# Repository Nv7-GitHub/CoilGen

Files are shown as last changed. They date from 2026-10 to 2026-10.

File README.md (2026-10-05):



## **IMPORTANT BUG FIX REGARDING FIELD SCALE IN "plot_various_error_metrics" PLOT - PLEASE UPDATE!**

 

<!-- ABOUT THE PROJECT -->

The CoilGen Project is a community-based tool for the generation of coil Layouts within the MRI/NMR environment. It is based on a boundary element method and generates an interconnected non-overlapping wire-tracks on 3D support structures. The focus of this work is post processing.

The user must specify a target field (e.g., bz(x,y,z)=y for a constant gradient in the y-direction) and a surface mesh geometry (e.g., a cylinder defined in an .stl file). The code then generates a coil layout in the form of a non-overlapping, interconnected wire trace to achieve the desired field.

## pyCoilGen: A Python Implementation
The author has supported the creation of **pyCoilGen**, a translation of this CoilGen Project to Python. The code is available on [GitHub](https://github.com/kev-m/pyCoilGen) and
documentation is available on [ReadTheDocs](https://pycoilgen.readthedocs.io/).

A full description is given in the following publication: https://onlinelibrary.wiley.com/doi/10.1002/mrm.29294

<!-- GETTING STARTED -->
## Getting Started

Check the documentation to get started

### Installation

1. Download and extract the file of the CoilGen repository
2. Run one of the examples in the folder "Examples"

The project requires MATLAB and optionally FastHenry2 for calculation of the coil inductance.  The MATLAB version should not be older than 2020A.

### Flex PCB export for KiCad

Cylindrical coils can be built as rolled 2-layer flex PCBs:
- **Slit-cylinder design:** the coil is designed on a cylinder with an axial slit (`'create slit cylinder mesh'`), so no track crosses the seam of the rolled board.
- **Export:** `export_kicad_flex_pcb` writes a KiCad board with both layers in series, variable-width traces and design rules, so KiCad's DRC checks every turn.
- **Re-simulation:** `import_kicad_flex_pcb` reads the board back and re-simulates the manufactured copper with CoilGen. The result works with the plotting functions.

See [Documentation/KiCad_flex_PCB_export.md](Documentation/KiCad_flex_PCB_export.md). The examples are:
- `Examples/halbach_flex_pcb_gradient_set.m`, which designs, exports, checks and re-simulates a 3-axis gradient set for a small Halbach magnet;
- `Examples/view_flex_pcb_coils.m`, which shows that set in 3D;
- `Examples/check_flex_pcb_boards.m`, which runs the independent board checks (KiCad DRC, same-net clearance, manufacturer limits, full-width field).

Manufacturer stackups and limits are kept as JSON profiles in `KiCad_flex_PCBs/fab_profiles/` (JLCPCB 2-layer flex, 1 oz, 0.2 mm for the example). Each board also has a STEP model of the rolled board (`<coil>.step.zip`: board, copper and silkscreen as separate colored bodies) made with `export_rolled_step`. Regenerate it whenever the board changes.

### Algorithm overview

plot

<!-- LICENSE -->
## License

 See `LICENSE.txt` for more information.

<p align="right">(<a href="#top">back to top</a>)</p>

<!-- CONTACT -->
## Contact

Philipp Amrein, Github User: Philipp-MR 

Project Link: [https://github.com/Philipp-MR/CoilGen]

<p align="right">(<a href="#top">back to top</a>)</p>

## Citation

For citation of this work, please refer to the following publication:
https://onlinelibrary.wiley.com/doi/10.1002/mrm.29294
https://doi.org/10.1002/mrm.29294

<p align="right">(<a href="#top">back to top</a>)</p>

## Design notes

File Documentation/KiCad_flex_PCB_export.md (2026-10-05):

# Flex PCB gradient coils with CoilGen and KiCad

This guide covers the full workflow for building CoilGen coils as rolled 2-layer flex PCBs:

1. Design the coil on a cylinder with a slit (the seam of the rolled board).
2. Pick the manufacturer profile (stackup, limits, design values).
3. Export it as a KiCad board with both copper layers in series, the stackup and design rules included, plus a STEP model of the rolled board.
4. Check the board: KiCad's DRC, a same-net check the DRC can't do, and the manufacturer limits.
5. Read the board back into CoilGen and re-simulate the copper that will actually be made.
6. Look at the coils in 3D with CoilGen's plotting functions.
7. Build and align the coils.

The worked example is a 3-axis gradient set for a 45 mT Halbach magnet: `Examples/halbach_flex_pcb_gradient_set.m`. It runs steps 1–5 for all three coils.

| File | Purpose |
|---|---|
| `sub_functions/build_slit_cylinder_mesh.m` | Cylinder mesh with an axial slit (`'create slit cylinder mesh'`). |
| `sub_functions/export_kicad_flex_pcb.m` | CoilGen result → `.kicad_pcb` + `.kicad_pro`. |
| `sub_functions/import_kicad_flex_pcb.m` | `.kicad_pcb` → CoilGen result, re-evaluated with CoilGen's own field routines. |
| `sub_functions/strip_coilgen_result.m` | Keeps only the fields the plotting functions need, so a result can be saved compactly. |
| `Examples/halbach_flex_pcb_gradient_set.m` | Designs, exports, checks and re-simulates the Halbach gradient set. |
| `sub_functions/export_rolled_step.m` | STEP model of the board rolled onto its cylinder (board body, copper, silkscreen as separate colored bodies), zipped for git. |
| `sub_functions/rolled_flex_pcb_step.py` | Builds that STEP: reads the board with KiCad's Python module and wraps it onto the cylinder with OpenCASCADE. |
| `sub_functions/find_kicad_cli.m` | Locates KiCad's command-line tool. |
| `sub_functions/run_kicad_cli.m` | Runs `kicad-cli` (or Python) with a time limit (Java `ProcessBuilder`, not `system()`). |
| `sub_functions/check_kicad_flex_pcb.m` | Independent checks of a board file: KiCad DRC, same-net clearance, manufacturer limits, full-width field. |
| `Examples/check_flex_pcb_boards.m` | Runs those checks on the three boards. |
| `Examples/view_flex_pcb_coils.m` | 3D views and field plots of the re-simulated boards. |
| `KiCad_flex_PCBs/fab_profiles/` | Manufacturer profiles (JSON): stackup, fab limits and design values. `jlcpcb_flex_2layer_1oz_25um_0p2mm.json` is used for the example. |
| `KiCad_flex_PCBs/halbach_45mT_gradient_set/` | One KiCad project folder per coil, `coil_summary.txt` for the set. |

## Coordinate frames

CoilGen always optimizes the field component along its own `z` axis, so that axis has to be the main-field (B0) direction. In a Halbach magnet B0 runs across the bore, so the coil cylinder is rotated 90° about `y`. Its axis then lies along CoilGen's `x`.

| Magnet | CoilGen |
|---|---|
| `x` (B0; left → right looking down the bore) | `z` |
| `y` (down, looking down +z with +x to the right) | `-y` |
| `z` (down the bore) | `x` |

Each coil is the gradient of B0 along one magnet axis:
- the Z coil gives dBx/dz;
- the Y coil gives dBx/dy;
- the X coil gives dBx/dx.

CoilGen's plots use the CoilGen frame.

On the board, `x` is the arc length around the circumference and `y` is the axial position (+axial points up on the board). `F.Cu` is the outside of the rolled cylinder.

## 1. Design on a slit cylinder

When the rolled board closes into a tube, its two edges meet at a seam, and no track can cross it. The coil is therefore designed on a cylinder with a narrow axial slit. CoilGen never lets current cross a mesh boundary, so the optimizer itself keeps the seam free of current.

```matlab
coil_out=CoilGen( ...
    'field_shape_function','x', ...
    'coil_mesh_file','create slit cylinder mesh', ...
    'slit_cylinder_mesh_parameter_list',[length radius 60 40 0 1 0 pi/2 slit_angle slit_width], ...
    'surface_is_cylinder_flag',false, ...
    'skip_postprocessing',true, ...   % the exporter builds the wiring itself
    ... );                            % target region, levels, regularization as usual
```

`slit_cylinder_mesh_parameter_list` takes the same values as `cylinder_mesh_parameter_list`, plus two more:
- **`slit_angle`:** the slit centre in radians, as `atan2(y,x)` *before* the rotation is applied.
- **`slit_width`:** the arc width kept free of current, in meters (3 mm in the example).

**Where to put the slit.** Run the closed-cylinder design first, then take the angle where the largest `|stream_function|` along the axial line is smallest. In the example:
- **Z and Y:** both have such a line, at 1.5% and 0.4% of the peak, so the slit costs nothing.
- **X:** its best line still carries 23% of the peak, but the slit design kept the efficiency of the closed one.

Note that `CoilGen` removes `sub_functions` from the path when it returns. Run `addpath('sub_functions')` before calling the exporter or importer.

## 2. Manufacturer profile

The board is made for a specific flex process, described in a JSON profile under `KiCad_flex_PCBs/fab_profiles/`. The example uses `jlcpcb_flex_2layer_1oz_25um_0p2mm.json`, taken from [JLCPCB's flex capabilities](https://jlcpcb.com/capabilities/flex-pcb-capabilities) (checked 2026-10-05).

The profile has three parts:
- **`stackup`.** Coverlay (PI 25 µm + adhesive 25 µm), 35 µm (1 oz) copper, 25 µm polyimide core, 35 µm copper, coverlay, ENIG finish, 0.2 mm total. The board's KiCad stackup, its thickness, and the copper spacing used for the field and inductance (0.06 mm centre to centre) all come from here.
- **`fab_limits`.** JLCPCB's minimums:

  | Rule | Limit |
  |---|---|
  | Trace width and spacing (1 oz) | 4 mil (0.1016 mm) |
  | Trace width tolerance | ±20 % |
  | Via | 0.3 mm drill, 0.55 mm pad |
  | Via ring to trace | 0.1 mm |
  | Hole to copper | 0.2 mm |
  | Copper to edge | 0.3 mm |
  | Coverlay opening | 0.1 mm larger than the pad, ≥ 0.15 mm from traces |
  | Silkscreen | text ≥ 1 mm high, lines ≥ 0.15 mm, ≥ 0.15 mm from pads |
  | Board size | up to 234 × 490 mm |
  | Bend radius | ≥ 10 × thickness for 2 layers |

  These go into the `.kicad_pro` design rules.
- **`design`.** The values the exporter actually uses, with margin over the limits: 0.15 mm clearance (also the KiCad net-class clearance), 0.3 mm edge clearance, 0.6/0.3 mm vias.

Pass it to the exporter with `'fab_profile',file`. Options given explicitly still override the profile. After the export, every board is checked against the limits, and `report.fab_check` lists each rule with its value, its limit and whether it passes. For another manufacturer or stackup, copy the file and change the values.

## 3. Export to KiCad

```matlab
report=export_kicad_flex_pcb(coil_out,'my_coil.kicad_pcb','title','My coil', ...
    'positive_gradient',[1;0;0], 'axis_marks',{[0;0;-1],'-X LEFT'; [0;0;1],'+X RIGHT'}, 'axial_label','+Z into bore');
```

What the exporter builds:

- **Series 2-layer spirals.** Each group of nested contour loops becomes one spiral. It goes inwards on `F.Cu`, through one via inside the innermost turn, and back out on `B.Cu`. Both layers carry every turn, so the efficiency per ampere doubles compared with one layer.
- **No crossovers.** Each turn is opened over `cut_width`. The step to the next turn first crosses to that turn's opening, then follows the turn's own removed section into its start, so steps never run alongside a turn.
- **Inner via.** Each group's via is placed inside its innermost turn, as close to the opening as the clearances allow. Inner turns with no room for it are dropped and reported.
- **Routing channel.** The spirals open towards a copper-free axial band: a free band between the groups (the centre of the Z coil) or a margin beyond the end of the coil (X and Y). The groups are linked in series there on `F.Cu`, and a return trace runs back on `B.Cu` directly under the links. Each group's output continues right next to its input. Together this leaves no net circumferential current and almost no field from the wiring.
- **Feed tab.** A tab on the end edge of the board (the +axial end) sticks out past the end of the coil, so the rolled seam stays clean and there is room to solder the leads. It carries `J1` on `F.Cu` and `J2` on `B.Cu` directly behind it (a coaxial feed). The tab sits next to the seam, so the three coils' tabs end up at different angles. Feed and return run as a stacked pair (`F.Cu` over `B.Cu`) along the seam edge from the tab to the routing channel. With `positive_gradient` set, the pads are labelled `+`/`-` so that current into the `+` pad gives a positive gradient.
- **Variable trace width.** Each turn is cut into pieces of at most 1 mm, and each piece is made as wide as the space allows, up to `max_track_width`. The limits are:
  - the clearance to the neighbouring turns, which widen by the same rule;
  - the clearance to all fixed-width copper (steps, leads, links, ties, vias, pads);
  - the board edge;
  - the turn's own other parts where it comes back close to itself (narrow tips). Here the trace may even go below the base width.

  In the example this halves the resistance.
- **One net per turn.** Each turn on each layer is its own net, and consecutive turns are joined by KiCad net-tie footprints (`CoilGen:NetTie_Turn`). The DRC can therefore check the clearance between every pair of turns.
- **Silkscreen.** `axis_marks` draws an axial `F.SilkS` line where the rolled coil faces a given direction (for aligning it in the magnet). `axial_label` adds arrows for the axial direction.
- **Board setup and project file.** With a fab profile, the board gets its stackup (coverlay, copper, polyimide, ENIG, 0.2 mm) and the coverlay opening (`pad_to_mask_clearance`), and its vias are tented under the coverlay. The `.kicad_pro` gets the manufacturer limits as design rules, and the design clearance and via size as the net class.
- **Coordinate mapping.** The board-to-cylinder mapping is written into the title block (`CoilGen mapping: ...`), which the importer uses.

Exporter options (lengths in mm):

| Option | Default | Meaning |
|---|---|---|
| `track_width` | auto | Base trace width. Auto uses the smallest turn spacing minus the clearance. |
| `variable_width`, `max_track_width` | true, 4 | Widen each turn to the locally available space. |
| `clearance` | 0.15 | Copper clearance. Also written into the `.kicad_pro`. |
| `cut_width` | 6 | Length of the opening in each turn, where the spiral steps to the next turn. |
| `via_diameter`, `via_drill` | 0.6, 0.3 | Inner and link vias. |
| `edge_clearance` | 0.3 | Copper-to-edge clearance rule. |
| `seam_gap` | 0.5 | Gap between the two board edges at the seam once rolled. |
| `end_margin` | 1.5 | Board extension beyond the ends of the coil surface. |
| `tab_length`, `pad_size` | 10, 3 | Length of the feed tab past the end of the coil, and size of the solder pads. |
| `fab_profile` | '' | Manufacturer profile (JSON); sets the values below that aren't given explicitly, the stackup, the coverlay opening and the design rules, and the board is checked against it. |
| `copper_thickness` | 0.035 | Used for the resistance (1 oz = 0.035). From the profile if given. |
| `layer_gap` | 0.1 | `F.Cu`–`B.Cu` distance centre to centre, used for the field check. From the profile: dielectric + copper thickness. |
| `title`, `net_prefix` | | Board title and prefix for the net names. |
| `calc_inductance` | true | Filament (Neumann) inductance estimate. |
| `axis_marks` | {} | `{direction (3x1, coil frame), label; ...}`: alignment lines on `F.SilkS`. |
| `axial_label` | '' | Label with an arrow for the +axial board direction. |
| `positive_gradient` | [] | Gradient direction (3x1, coil frame) that counts as positive; sets the pad polarity labels. |

The `report` holds:
- the efficiency and gradient vector (mT/m/A) and the non-linearity, from Biot-Savart on the exported copper (both layers, links, subdivided onto the cylinder);
- the resistance and the track width minimum, mean and maximum;
- the smallest same-net gap;
- the inductance estimate, the turns per group and the number of dropped loops.

### STEP models

Each board folder has a 3D model of the board rolled onto its cylinder: `<coil>.step.zip`, which contains `<coil>.step`. It has four named, colored bodies:

| Body | What | Color |
|---|---|---|
| `Board` | the 0.2 mm board as a solid tube with the seam gap and the feed tab | yellow (coverlay) |
| `F.Cu` | copper on the outside (tracks and net ties) | copper |
| `B.Cu` | copper on the inside | copper |
| `F.SilkS` | silkscreen (alignment lines and text) | white |

Copper and silkscreen are surfaces, each layer merged into one body. As in KiCad's own STEP export they sit on the faces of the board body, which is centred on the middle of the copper stackup. Pads (the J1/J2 solder pads and the net-tie pads) and vias are left out; use `'include_pads',true` to keep the pads. The outlines are simplified to 0.02 mm (`'tolerance'`), well under the 0.15 mm clearance.

The coil diameter (65 / 70 / 75 mm) is the diameter of `F.Cu`. With the 0.2 mm stackup the board is about 0.25 mm smaller (ID) and 0.14 mm larger (OD), so the Z board is about 64.75 mm ID and 65.14 mm OD.

The example writes the models in the magnet frame (`'frame'`: bore along z, B0 along x), so the three files line up when you open them together: the coils nest at the right radii and the tabs come out of the +Z end at the angles in section 7. Each file is about 20 MB (about 4 MB zipped). Git keeps the zipped version and ignores the plain `.step`.

```matlab
export_rolled_step('KiCad_flex_PCBs/halbach_45mT_gradient_set/Z_gradient_bore_axis/Z_gradient_bore_axis.kicad_pcb', ...
    'frame',[0 0 1; 0 -1 0; 1 0 0]);   % CoilGen frame -> magnet frame
```

`rolled_flex_pcb_step.py` reads the board with KiCad's Python module (`pcbnew`, KiCad 8 or later), which merges the tracks of each layer and renders the silkscreen text. It then wraps each outline onto the cylinder. Every straight edge on the board becomes a helix on the cylinder, so the geometry is exact, not faceted. The cylinder (radius, seam angle, rotation) comes from the `CoilGen mapping` and `CoilGen cylinder` lines that `export_kicad_flex_pcb` writes into the title block.

It needs a Python with `cadquery-ocp`, `shapely` and `numpy`. `export_rolled_step` uses `.venv` in the CoilGen folder, or the Python given with `'python'` or in `COILGEN_PYTHON`:

```bash
python3.12 -m venv .venv      # cadquery-ocp has wheels up to Python 3.13
.venv/bin/pip install cadquery-ocp shapely numpy
```

It also runs on its own: `.venv/bin/python sub_functions/rolled_flex_pcb_step.py <board>.kicad_pcb [--frame ...] [--pads]`.

> **Regenerate the STEPs whenever a board changes.** That includes a re-export from CoilGen, a new fab profile, or an edit made in KiCad. `halbach_flex_pcb_gradient_set.m` exports them automatically after every board export. After a manual edit in KiCad, run `export_rolled_step` on the edited board, then commit the new `.step.zip` together with the `.kicad_pcb`.

## 4. Check the board

Each board is checked in several independent ways. `Examples/check_flex_pcb_boards.m` runs all of them on the `.kicad_pcb` files through `check_kicad_flex_pcb`. Because the checks read the board files themselves, they also cover anything edited in KiCad.

| Check | What it catches | Where |
|---|---|---|
| **KiCad DRC** | Shorts between nets, clearance between all nets (so between all turns), unconnected items (the series chain J1–J2), edge clearance, via and drill sizes, silkscreen size and clearance, coverlay openings | `kicad-cli pcb drc`, run by `check_kicad_flex_pcb` |
| **Same-net clearance** | A turn coming too close to itself, which the DRC can't see because it's one net | Exporter (`report.min_same_net_gap_mm`) and `check_kicad_flex_pcb` (from the file) |
| **Manufacturer limits** | Track width, clearance, vias, edge clearance, board size and bend radius against the fab profile | Exporter (`report.fab_check`) and `check_kicad_flex_pcb` |
| **Chain and polarity** | Branches, breaks or stray copper in the J1–J2 chain; whether J1→J2 gives the design polarity | `import_kicad_flex_pcb` (step 5) |
| **Field of the copper** | Efficiency, linearity and field error of the board copper, against the target and the ideal turns | Exporter (Biot-Savart) and `import_kicad_flex_pcb` (CoilGen's own routines) |
| **Full track width** | Whether the wide tracks change the field: each track is split into filaments across its width and compared with thin wires on its centre line | `check_kicad_flex_pcb` with `'coil_result'` |

**KiCad DRC.** It doesn't need a schematic, because every net is defined in the board file. With a fab profile, the `.kicad_pro` holds the manufacturer's limits as rules, and the design clearance and vias as the net class. To confirm that DRC really applies the project rules, run it on a copy of a board with an impossible rule (for example `min_track_width` = 5 mm). It then reports track-width violations; with the real rules it reports none. To run the DRC on its own:

```bash
cd KiCad_flex_PCBs/halbach_45mT_gradient_set
for f in */*.kicad_pcb; do kicad-cli pcb drc --severity-all -o "${f%.kicad_pcb}_drc.rpt" "$f"; done
```

**Same-net clearance.** KiCad doesn't check clearance *within* a net. A turn that came too close to itself (in a narrow tip, for example) would short part of the turn without any DRC error. The exporter narrows turns where this would happen, even below the base width, and reports the smallest same-net gap, warning when it's below the clearance. `check_kicad_flex_pcb` measures it again from the board file: it samples all tracks every 0.05 mm and compares parts of a net that are far apart along the track.

**Full track width.** The re-simulation (step 5) models every track as a thin wire along its centre. Splitting each track into 7 filaments across its real width changes the gradients by less than 0.1 % and the field by less than 0.05 % of its range, so the wide tracks don't affect the field. The current stays centred because the tracks widen symmetrically, and the copper is at least 12.5 mm from the target region.

**Results for the example boards:**
- **KiCad DRC:** 0 violations and 0 unconnected items on all three.
- **Same-net clearance:** at least 0.15 mm.
- **JLCPCB profile:** every limit met.
- **Re-simulation:** matches the design, and J1→J2 has the design polarity on all three.

## 5. Re-simulate the manufactured copper

```matlab
[pcb_out,pcb_check]=import_kicad_flex_pcb(coil_out,'my_coil.kicad_pcb');
```

The importer reads the board file itself (tracks, vias, net ties, pads) and follows the copper from `J1` to `J2`. It stops with an error if the chain branches, breaks, or leaves copper unused. It maps the path back onto the cylinder: `F.Cu` outside, `B.Cu` one `layer_gap` inside. The path then becomes the coil's `wire_path`, and CoilGen's own `evaluate_field_errors` and `calculate_gradient` evaluate it.

Because the board file is read, the result reflects the copper as it will be made, including any edits done in KiCad.

**Like-for-like comparison.** Both layers carry every turn, so the ideal reference is the same turns as closed loops on *both* layers. The importer adds the second-layer copy of the contour loops and halves the contour step, so that each ampere in the board counts as two steps of the stream function. The error metrics then compare like with like:
- **`layout`:** the board copper, against the target field;
- **`unconnected contours`:** the ideal closed turns on both layers, against the target field.

`pcb_out` has the same fields as a CoilGen result, so the functions in `plotting` work on it. `pcb_check` holds the number of segments, ties and vias, the copper length, the resistance from the actual trace widths, the gradient (mean and spread over the target region), CoilGen's error values, and whether current from J1 to J2 has the design polarity.

## 6. View the coils in 3D

`halbach_flex_pcb_gradient_set.m` saves a compact copy of each re-simulated result next to its board (`<coil>_coilgen_pcb.mat`, about 3 MB). To open the 3D views and field plots of all three coils without rerunning the design, run this in the MATLAB desktop:

```matlab
cd Examples
view_flex_pcb_coils
```

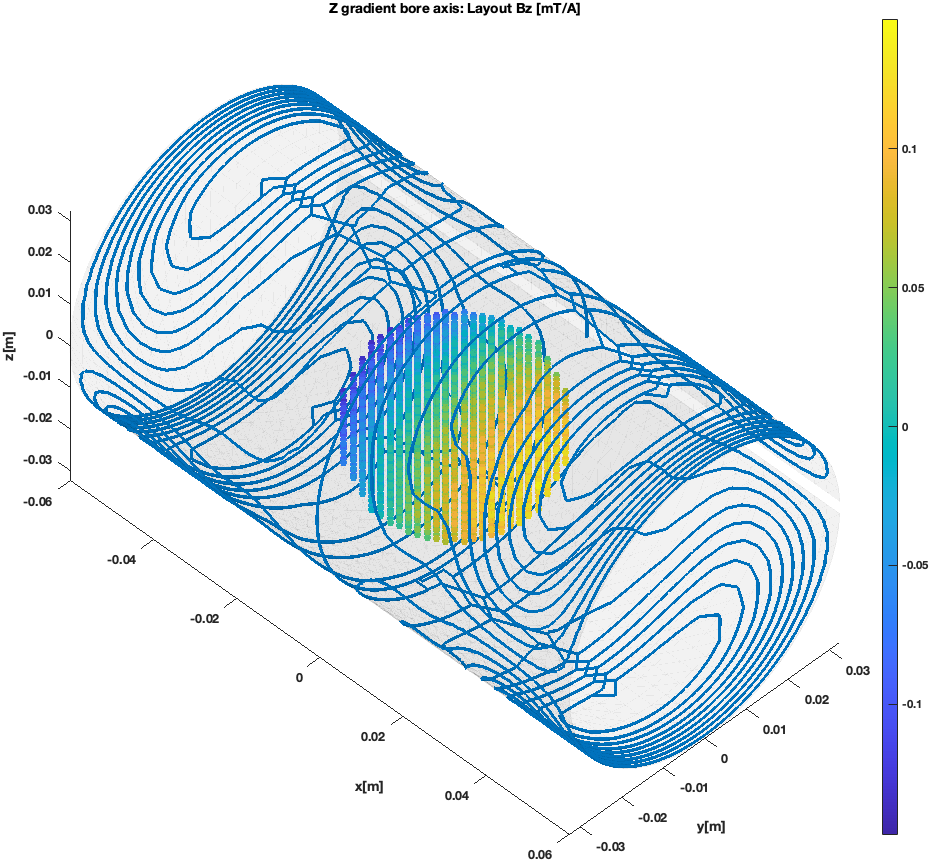
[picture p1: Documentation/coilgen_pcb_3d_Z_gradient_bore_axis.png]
Z coil, copper read back from the board, with the resulting field


The views show the actual PCB copper: the spirals with their steps between turns, the link ring and the seam. The field shown is the one this copper produces in the target region. In the 3D views, `plot_slit_seam` marks the seam (the slit where the rolled board's edges meet) as a red strip labelled "seam (PCB split)". You can call it after any 3D plot of a slit-cylinder coil: `plot_slit_seam(coil_layouts,1)`. Rotate the views with the rotate tool in the figure toolbar.

## Example results

All values are for the JLCPCB profile (1 oz copper, 25 µm polyimide, 0.2 mm) and 0.15 mm clearance, with variable trace width up to 4 mm. The inductance is a filament estimate (±15%), and V (L) is the voltage across it for a 100 µs ramp. The ±20 % trace width tolerance means the real resistance can be about −17 % / +25 % off the nominal value. All three boards meet every limit in the profile.

The coils are 120 mm long (the board is about 123–125 mm), centred on the 40 mm target region.

**24 V check (Z, the most demanding axis).** Nominal: 16.1 V + 2.7 V (100 µs ramp) ≈ 18.8 V. Worst case, with +25 % resistance from the trace width tolerance and the copper 30 °C warm (R ≈ 5.9 Ω): 22.6 V + 2.7 V ≈ 25.3 V. That is slightly over 24 V; a 150 µs ramp or 2 oz copper brings it back under. X and Y need about 4–5 V in all cases.

| Coil | Diameter | Track min/mean/max | Turns (both layers) | Efficiency | Non-linearity, 40 mm DSV | R | L | Current for target | V (R) | V (L) | Peak power |
|---|---|---|---|---|---|---|---|---|---|---|---|
| Z (bore axis), 28 mT/m | 65 mm | 0.70 / 1.54 / 4.0 mm | 72 | 7.34 mT/m/A | 0.69 % | 4.2 Ω | 72 µH | 3.81 A | 16.1 V | 2.7 V | 62 W |
| Y, 12 mT/m | 70 mm | 1.05 / 1.82 / 4.0 mm | 72 | 17.9 mT/m/A | 0.70 % | 5.1 Ω | 139 µH | 0.67 A | 3.4 V | 0.9 V | 2.3 W |
| X (B0 axis), 12 mT/m | 75 mm | 1.05 / 2.19 / 4.0 mm | 62 | 14.0 mT/m/A | 0.16 % | 3.7 Ω | 115 µH | 0.86 A | 3.2 V | 1.0 V | 2.7 W |

CoilGen re-simulation of the copper read back from the boards. The field errors are the deviation from the target field, relative to its maximum; "ideal" means the same turns as closed loops on both layers.

| Coil | Gradient (mean ± spread) | R from board | Field error, board copper (max / mean) | Field error, ideal turns (max / mean) | J1→J2 |
|---|---|---|---|---|---|
| Z | 7.34 ± 0.05 mT/m/A | 4.23 Ω | 1.37 / 0.37 % | 1.33 / 0.31 % | design polarity |
| Y | 17.88 ± 0.19 mT/m/A | 5.05 Ω | 2.70 / 0.69 % | 0.79 / 0.19 % | design polarity |
| X | 14.03 ± 0.03 mT/m/A | 3.73 Ω | 0.61 / 0.23 % | 0.68 / 0.30 % | design polarity |

The wiring adds almost nothing to the Z and X coils. On the Y coil, the extra error comes from 4 small loops that sat as side branches inside other turns. They can't be reached on two layers, so the exporter dropped them (see Limitations).

**Why Z needs the most power.** With the main field across the bore, a gradient along the bore can't use a Maxwell-pair-like layout, so it's built from four saddle-shaped groups. At a fixed gradient the power doesn't depend on the number of turns: fewer turns lower the voltage but raise the current by the same factor. Only these reduce the power:
- more copper: wider traces (as done here) or thicker copper (2 oz halves the resistance again);
- a lower gradient;
- a longer coil.

Renders of the top side (`F.Cu`):

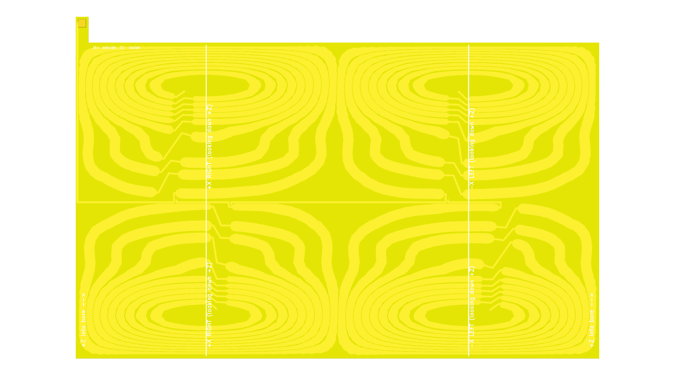
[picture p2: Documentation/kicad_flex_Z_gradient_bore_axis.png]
Z gradient

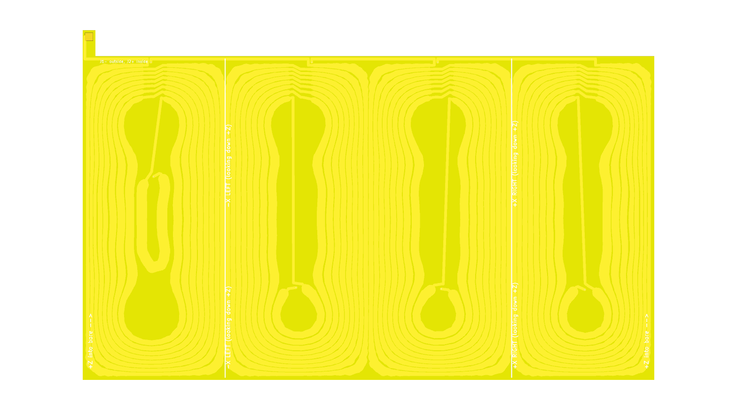
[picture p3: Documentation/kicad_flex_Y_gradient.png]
Y gradient

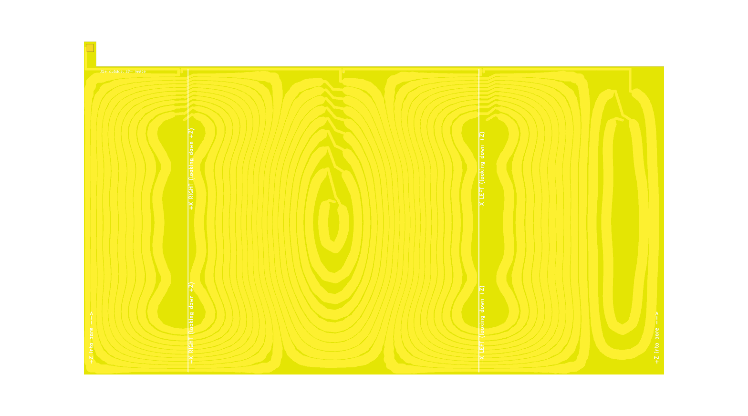
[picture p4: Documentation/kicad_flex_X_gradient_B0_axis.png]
X gradient


## 7. Building the coils

- The boards are made for JLCPCB flex: 2 layers, 1 oz copper, 25 µm polyimide, 0.2 mm, ENIG, yellow coverlay. The KiCad stackup and design rules match, and all limits are met. For another manufacturer, make a new profile (see section 2) and re-export.
- Optional: order a 0.2 mm PI stiffener under the solder tabs (JLCPCB offers it), so the tabs stay flat while soldering.
- Roll each board with `F.Cu` outside. The two seam edges meet with a `seam_gap` gap, and no track crosses the seam. The rolled boards are about 123–125 mm long, plus the 10 mm feed tab sticking out of the +Z end (to about +72–73 mm from the coil centre).
- Turn each rolled coil so that, looking down the bore in +Z (B0 from left to right):
  - the `-X LEFT` silkscreen line sits at the left side of the bore;
  - the `+X RIGHT` line sits at the right side;
  - the `+Z into bore` arrows point down the bore.
- Solder the leads to `J1` (outside face of the tab) and `J2` (inside face), and twist them. Current into the pad marked `+` gives a positive gradient; on the Y coil that is `J2`.
- **Tab and seam angles.** These are measured counterclockwise from the +X line, as seen from the +Z end (where the tabs come out) with +X to the right and +Y up. Viewed from the −Z end, use 360° − θ. Each tab starts at its coil's seam edge and is 5 mm wide.

  | Coil | Diameter | Seam gap | Tab |
  |---|---|---|---|
  | Z | 65 mm (inner) | 269.6°–270.4° | 270.4°–279.3° |
  | Y | 70 mm (middle) | 89.6°–90.4° | 90.4°–98.6° |
  | X | 75 mm (outer) | 294.6°–295.4° | 295.4°–303.0° |

  None of the tabs overlap. Leave 1–2° of clearance on each side of any opening for the tabs.
- Nest the coils: Z (65 mm) inside, then Y (70 mm), then X (75 mm), 2.5 mm apart radially. Line up the axial centres.

## Limitations

- Only single-part coils designed on a `'create slit cylinder mesh'` surface are supported.
- When a loop contains more than one nested set of loops, only the largest branch is kept, and the others are dropped with a warning. These small side-branch loops can't be reached on two layers. The re-simulation shows their effect: about 2.4 % more maximum error on the Y coil.
- Inner turns with no room for the via are dropped and counted in `report.dropped_loops`.
- The inductance is an estimate (±15%), not a FastHenry result. The inter-layer capacitance, and so the self-resonance, isn't calculated. Measure the self-resonance once a coil is built, and check it is well away from your RF frequency.
- The importer expects boards written by `export_kicad_flex_pcb`: it needs the mapping in the title block and the `CoilGen:NetTie_Turn` and `CoilGen:SolderPad` footprints. Tracks you edit or add in KiCad are fine, as long as the copper stays one chain from J1 to J2.

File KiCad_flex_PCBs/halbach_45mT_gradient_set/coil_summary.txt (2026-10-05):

coil                     track  turns       eff   nonlin       R        L       I     V_R      V_L   P_peak
                          [mm]         [mT/m/A]      [%]   [Ohm]     [uH]     [A]     [V]      [V]      [W]
Z_gradient_bore_axis      0.70     72      7.34     0.69    4.23     71.8    3.81    16.1      2.7     61.6
Y_gradient                1.05     72     17.88     0.70    5.05    138.7    0.67     3.4      0.9      2.3
X_gradient_B0_axis        1.05     62     14.03     0.16    3.73    114.8    0.86     3.2      1.0      2.7
Track width min/mean/max [mm] and smallest gap within a net (not checked by the KiCad DRC):
Z_gradient_bore_axis   0.70 / 1.54 / 4.00   same-net gap 0.169 mm
Y_gradient             1.05 / 1.82 / 4.00   same-net gap 0.150 mm
X_gradient_B0_axis     1.05 / 2.19 / 4.00   same-net gap 0.150 mm
V_L assumes a ramp time of 100 us to the target gradient; L is a filament estimate (+-15%).

CoilGen re-simulation of the copper read back from the .kicad_pcb files (J1 to J2):
coil                    gradient       std        R   err layout [%]    err ideal [%]     J1->J2
                        [mT/m/A]  [mT/m/A]    [Ohm]       max / mean       max / mean   polarity
Z_gradient_bore_axis        7.34     0.048     4.23    1.37 /  0.37     1.33 /  0.31  as design
Y_gradient                 17.88     0.193     5.05    2.70 /  0.69     0.79 /  0.19  as design
X_gradient_B0_axis         14.03     0.030     3.73    0.61 /  0.23     0.68 /  0.30  as design
err: deviation from the target field relative to its maximum; ideal = the same turns as closed loops on both layers.

Manufacturer check against JLCPCB flex, 2 layers, 1 oz outer copper, 25 um polyimide dielectric, 0.2 mm:
Z_gradient_bore_axis   all limits met (min track 0.70 mm, board 203.7 x 133.0 mm)
Y_gradient             all limits met (min track 1.05 mm, board 219.4 x 134.2 mm)
X_gradient_B0_axis     all limits met (min track 1.05 mm, board 235.1 x 134.7 mm)
Resistance tolerance from the +-20% track width tolerance: about -17% / +25%.

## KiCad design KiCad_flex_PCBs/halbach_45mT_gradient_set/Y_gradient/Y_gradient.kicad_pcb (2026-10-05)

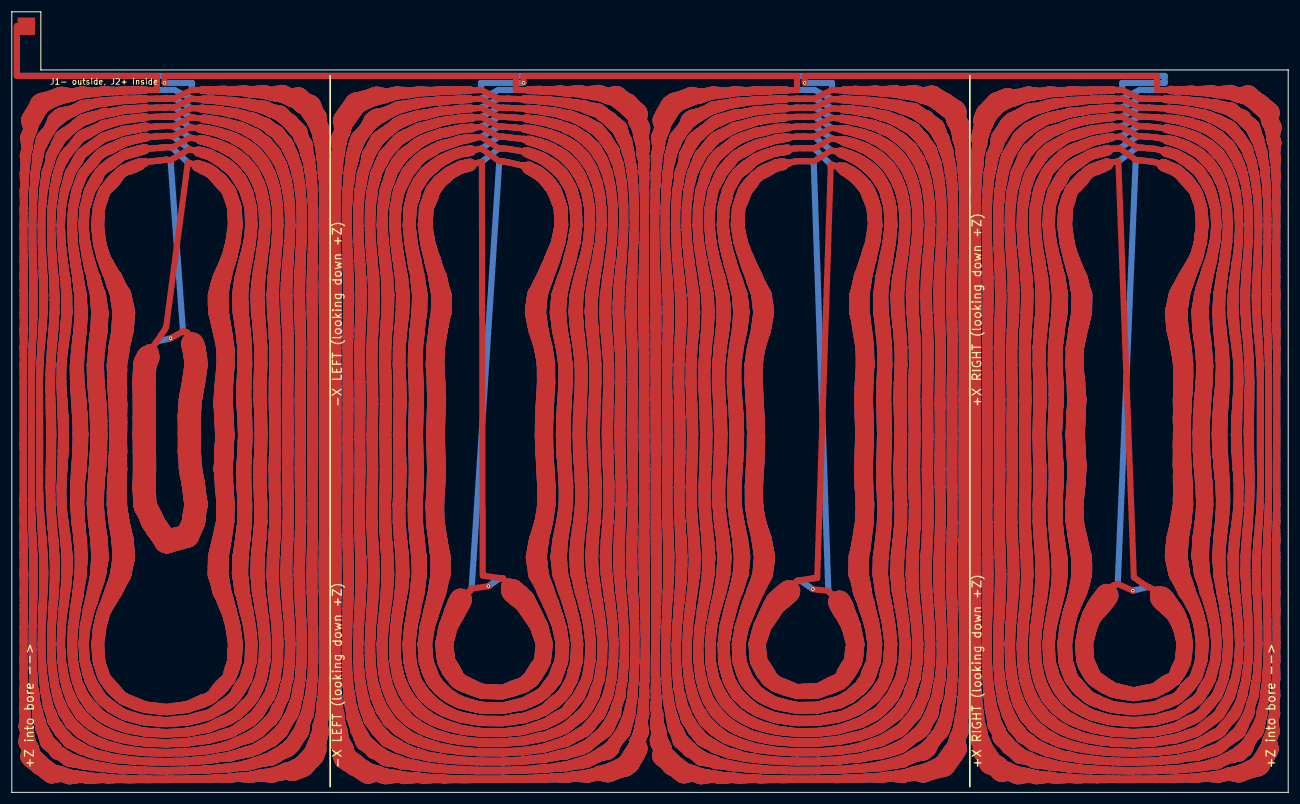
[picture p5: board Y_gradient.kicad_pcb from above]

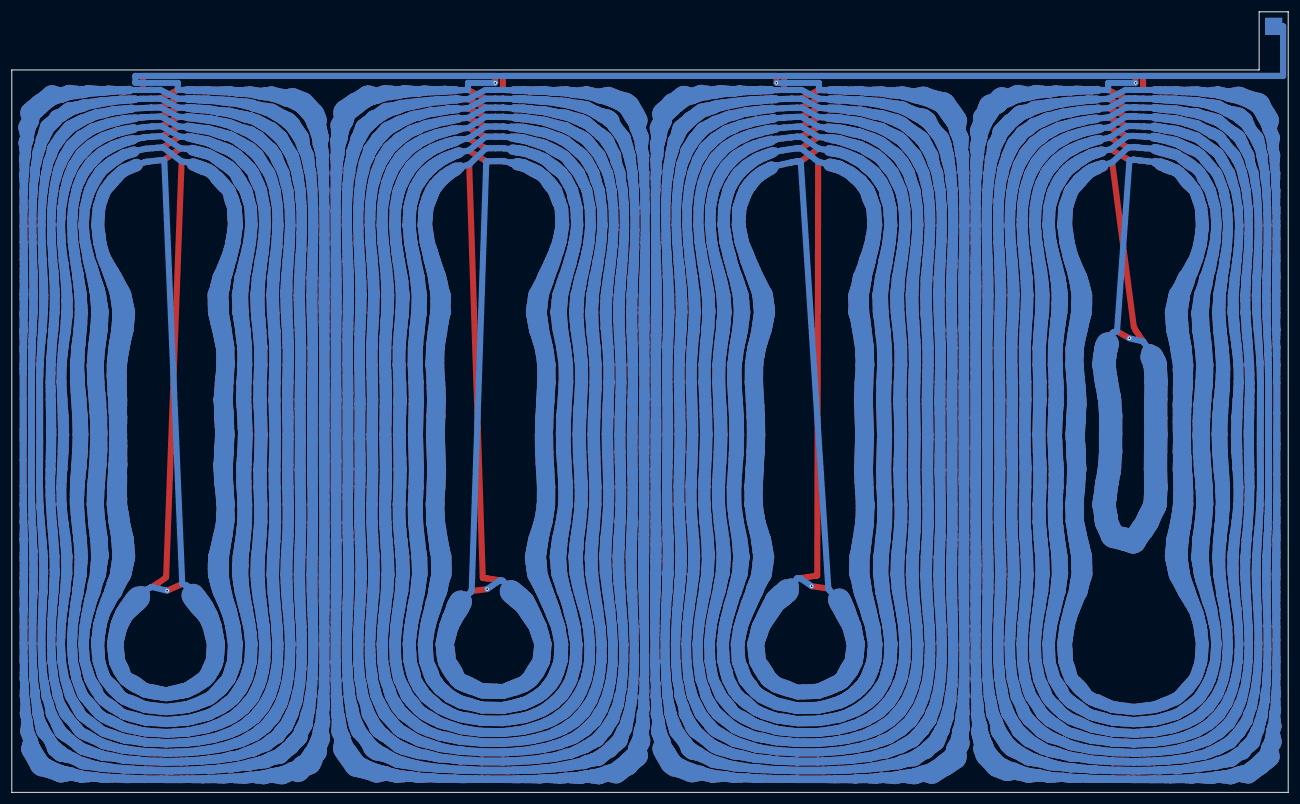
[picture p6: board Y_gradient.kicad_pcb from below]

Board: 2 copper layers, 219.4 x 134.2 mm, 70 parts (33 on the bottom side), 69 nets.

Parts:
J1-, J2+: SolderPad
NT1, NT2, NT3, NT4, NT5, NT6, NT7, NT8, NT9, NT10, NT11, NT12, NT13, NT14, NT15, NT16, NT17, NT18, NT19, NT20, NT21, NT22, NT23, NT24, NT25, NT26, NT27, NT28, NT29, NT30, NT31, NT32, NT33, NT34, NT35, NT36, NT37, NT38, NT39, NT40, NT41, NT42, NT43, NT44, NT45, NT46, NT47, NT48, NT49, NT50, NT51, NT52, NT53, NT54, NT55, NT56, NT57, NT58, NT59, NT60, NT61, NT62, NT63, NT64, NT65, NT66, NT67, NT68: NetTie; NetTie_Turn

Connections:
COIL_A: J1-.1, NT1.1
G1_B1: NT17.2, NT18.1
G1_B2: NT16.2, NT17.1
G1_B3: NT15.2, NT16.1
G1_B4: NT14.2, NT15.1
G1_B5: NT13.2, NT14.1
G1_B6: NT12.2, NT13.1
G1_B7: NT11.2, NT12.1
G1_B8: NT10.2, NT11.1
G1_T1: NT1.2, NT2.1
G1_T2: NT2.2, NT3.1
G1_T3: NT3.2, NT4.1
G1_T4: NT4.2, NT5.1
G1_T5: NT5.2, NT6.1
G1_T6: NT6.2, NT7.1
G1_T7: NT7.2, NT8.1
G1_T8: NT8.2, NT9.1
G1_T9: NT9.2, NT10.1
G2_B1: NT34.2, NT35.1
G2_B2: NT33.2, NT34.1
G2_B3: NT32.2, NT33.1
G2_B4: NT31.2, NT32.1
G2_B5: NT30.2, NT31.1
G2_B6: NT29.2, NT30.1
G2_B7: NT28.2, NT29.1
G2_B8: NT27.2, NT28.1
G2_T1: NT18.2, NT19.1
G2_T2: NT19.2, NT20.1
G2_T3: NT20.2, NT21.1
G2_T4: NT21.2, NT22.1
G2_T5: NT22.2, NT23.1
G2_T6: NT23.2, NT24.1
G2_T7: NT24.2, NT25.1
G2_T8: NT25.2, NT26.1
G2_T9: NT26.2, NT27.1
G3_B1: NT51.2, NT52.1
G3_B2: NT50.2, NT51.1
G3_B3: NT49.2, NT50.1
G3_B4: NT48.2, NT49.1
G3_B5: NT47.2, NT48.1
G3_B6: NT46.2, NT47.1
G3_B7: NT45.2, NT46.1
G3_B8: NT44.2, NT45.1
G3_T1: NT35.2, NT36.1
G3_T2: NT36.2, NT37.1
G3_T3: NT37.2, NT38.1
G3_T4: NT38.2, NT39.1
G3_T5: NT39.2, NT40.1
G3_T6: NT40.2, NT41.1
G3_T7: NT41.2, NT42.1
G3_T8: NT42.2, NT43.1
G3_T9: NT43.2, NT44.1
G4_B1: J2+.1, NT68.2
G4_B2: NT67.2, NT68.1
G4_B3: NT66.2, NT67.1
G4_B4: NT65.2, NT66.1
G4_B5: NT64.2, NT65.1
G4_B6: NT63.2, NT64.1
G4_B7: NT62.2, NT63.1
G4_B8: NT61.2, NT62.1
G4_T1: NT52.2, NT53.1
G4_T2: NT53.2, NT54.1
G4_T3: NT54.2, NT55.1
G4_T4: NT55.2, NT56.1
G4_T5: NT56.2, NT57.1
G4_T6: NT57.2, NT58.1
G4_T7: NT58.2, NT59.1
G4_T8: NT59.2, NT60.1
G4_T9: NT60.2, NT61.1

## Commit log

2026-10-02 Add KiCad 2-layer flex PCB exporter and Halbach gradient set
    - New mesh option 'create slit cylinder mesh' (build_slit_cylinder_mesh):
    cylinder with an axial slit so no current crosses the seam of a rolled
    flex PCB.
    - export_kicad_flex_pcb: turns each loop group into a series 2-layer
    spiral (in on F.Cu, via, out on B.Cu), links the groups in a copper free
    channel with a return trace under the links, adds a coaxial J1/J2 feed
    tab, one net per turn joined by net ties so KiCad DRC checks every turn,
    and writes the design rules to the .kicad_pro. Reports efficiency,
    linearity, resistance and an inductance estimate from the exported copper.
    - Example halbach_flex_pcb_gradient_set.m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
    [X_gradient_B0_axis.kicad_pcb, Y_gradient.kicad_pcb, Z_gradient_bore_axis.kicad_pcb]
2026-10-02 Add alignment marks and gradient polarity labels to flex PCB export
    - axis_marks: axial F.SilkS lines where the rolled coil faces a given
    direction (used for -X left / +X right of the Halbach bore)
    - axial_label: +Z bore direction arrows
    - positive_gradient: pads labelled so current into the '+' pad gives a
    positive gradient (Y coil is J2+)
    [X_gradient_B0_axis.kicad_pcb, Y_gradient.kicad_pcb, Z_gradient_bore_axis.kicad_pcb]
2026-10-02 Ignore KiCad lock files
2026-10-02 Widen flex PCB traces to the locally available space
    Each turn is split into <=1 mm pieces that are made as wide as the
    clearance to the neighbouring turns, fixed-width copper and the board edge
    allows (up to max_track_width, default 4 mm). Steps between turns, leads,
    links, ties and vias keep the base width. Resistance of the Halbach set
    drops from 9.2/9.8/10.7 to 4.1/5.2/5.0 Ohm (Z/Y/X); Z at 28 mT/m now needs
    3.8 A at ~16 V + 2.7 V ramp. All boards pass KiCad DRC.
    [X_gradient_B0_axis.kicad_pcb, Y_gradient.kicad_pcb, Z_gradient_bore_axis.kicad_pcb]
2026-10-02 Put each flex PCB in its own KiCad project folder
    [X_gradient_B0_axis.kicad_pcb, Y_gradient.kicad_pcb, Z_gradient_bore_axis.kicad_pcb]
2026-10-02 Prevent same-net self-overlap in flex PCB turns
    KiCad's DRC can't check clearance within a net, and the innermost turn of
    one Y group pinched to 0.82 mm, so its 0.95 mm track overlapped itself.
    Turns are now narrowed below the base width where they come close to
    themselves, and the exporter reports the smallest same-net gap
    (min_same_net_gap_mm, warning below the clearance). All three boards:
    DRC clean and same-net gap >= 0.15 mm.
    [X_gradient_B0_axis.kicad_pcb, Y_gradient.kicad_pcb, Z_gradient_bore_axis.kicad_pcb]
2026-10-02 Re-simulate the KiCad boards with CoilGen and view them in 3D
    - import_kicad_flex_pcb: reads a board written by export_kicad_flex_pcb,
    follows the copper from J1 to J2 (errors on branches, breaks or unused
    copper), maps it back onto the cylinder and re-evaluates the field with
    CoilGen's evaluate_field_errors and calculate_gradient. The ideal
    reference is the same turns on both layers, so the metrics compare like
    with like. The result works with the plotting functions.
    - The exporter writes the board-to-cylinder mapping into the title block.
    - strip_coilgen_result: compact results for plotting; the example saves
    one per board, view_flex_pcb_coils.m shows them in 3D.
    - Halbach exam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
    [X_gradient_B0_axis.kicad_pcb, Y_gradient.kicad_pcb, Z_gradient_bore_axis.kicad_pcb]
2026-10-02 Mark the PCB seam in the 3D views of slit-cylinder coils
    plot_slit_seam draws the slit (where the rolled board's edges meet) as a
    red strip; used by view_flex_pcb_coils.m and the Halbach example.
2026-10-02 Move the feed tab to the end edge of the flex PCBs
    The J1/J2 tab now sticks out past the +axial end of the coil instead of
    out of the seam, so the rolled seam is clean and there is room to solder
    the leads. Feed and return run as a stacked F.Cu/B.Cu pair along the seam
    edge to the routing channel. Larger pads (3 mm) on a 10 mm tab. The tabs
    of the three coils sit at their seams: 12, 1 and 6 o'clock looking down +Z.
    All boards: DRC clean, same-net gap >= 0.15 mm, re-simulation unchanged.
    [X_gradient_B0_axis.kicad_pcb, Y_gradient.kicad_pcb, Z_gradient_bore_axis.kicad_pcb]
2026-10-05 Add JLCPCB flex fab profile, stackup, fab checks and board check script
    - KiCad_flex_PCBs/fab_profiles/jlcpcb_flex_2layer_1oz_25um_0p2mm.json:
    JLCPCB 2-layer flex (1 oz, 25 um PI, 0.2 mm) stackup, manufacturer
    limits and the design values used.
    - export_kicad_flex_pcb 'fab_profile': design values, layer spacing
    (0.06 mm), KiCad stackup (coverlay, Cu, PI, ENIG, 0.2 mm), coverlay
    opening (0.1 mm) and .kicad_pro rules from the profile; every board is
    checked against the limits (report.fab_check).
    - check_kicad_flex_pcb / Examples/check_flex_pcb_boards.m: independent
    checks on the board files (KiCad DRC, same-net clearance, manufacturer
    limits, full-width field).
    - Boards regenerat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
    [X_gradient_B0_axis.kicad_pcb, Y_gradient.kicad_pcb, Z_gradient_bore_axis.kicad_pcb]
2026-10-05 Add STEP models of the flex PCBs
    - export_kicad_step: flat 3D model of a board with kicad-cli (board body,
    copper, silkscreen), zipped (<coil>.step.zip, 15-22 MB; the plain .step
    is 90-125 MB, over GitHub's limit, and is git-ignored).
    - find_kicad_cli: shared locator for kicad-cli.
    - The Halbach example regenerates the STEPs after every board export.
    - STEP models of the three gradient boards.
    - Documentation: STEP models and when to regenerate them.
2026-10-05 Keep the exported .kicad_pro when kicad-cli loads a board
    kicad-cli rewrites the project file in its own format (same rules) when
    it runs DRC or the STEP export; export_kicad_step and
    check_kicad_flex_pcb now restore the exported file afterwards.
2026-10-05 Regenerate the gradient set at 65 / 70 / 75 mm, 120 mm long
    - Coils now rolled at 65 (Z), 70 (Y) and 75 mm (X), 120 mm long.
    Z 7.34 mT/m/A, 4.23 ohm, 72 uH, 3.81 A at 28 mT/m (~18.8 V);
    Y 17.9 mT/m/A, 5.05 ohm, 139 uH; X 14.0 mT/m/A, 3.73 ohm, 115 uH.
    - All boards: KiCad DRC clean, same-net gap >= 0.15 mm, all JLCPCB
    limits met, re-simulation from the board files matches the design,
    full-width traces change the field by < 0.05 %.
    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
    [X_gradient_B0_axis.kicad_pcb, Y_gradient.kicad_pcb, Z_gradient_bore_axis.kicad_pcb]
2026-10-05 STEP models: board, copper tracks and silkscreen only
    export_kicad_step leaves out pads (solder pads, net ties) and vias by
    default ('include_pads' / 'include_vias'); vias are stripped from a
    temporary copy since kicad-cli exports them with the tracks. STEPs of
    the three boards regenerated.
2026-10-05 Rolled STEP models of the flex PCBs replace KiCad's flat export
    - rolled_flex_pcb_step.py reads each board with KiCad's Python module
    (merged tracks, net ties, silkscreen incl. text, outline) and wraps it
    onto the coil's cylinder with OpenCASCADE: board edges become exact
    helices. One named, colored body per layer: Board (0.2 mm solid tube
    with tab), F.Cu, B.Cu, F.SilkS (surfaces on the board faces). About
    20 MB per board (4 MB zipped) instead of 88-121 MB.
    - export_rolled_step.m runs it from MATLAB with a time limit; the example
    calls it after every board export, in the magnet frame.
    - export_kicad_flex_pcb writes the cylinder (radius, seam angle, rotation)
    into the title bloc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
    [X_gradient_B0_axis.kicad_pcb, Y_gradient.kicad_pcb, Z_gradient_bore_axis.kicad_pcb]
